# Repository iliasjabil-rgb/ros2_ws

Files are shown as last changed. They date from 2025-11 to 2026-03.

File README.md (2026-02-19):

# 🤖 Firmware Embarqué - Robot SRS

Ce dépôt contient le code source bas niveau (C++) pour les microcontrôleurs du robot SRS. Le système est divisé en deux cartes distinctes pour garantir la sécurité matérielle, la séparation des flux de puissance, et la gestion des périphériques.

## 🏗️ Architecture du Système

Le code communique avec un ordinateur central (Raspberry Pi / PC sous ROS 2) via un protocole série JSON non-bloquant à 115200 bauds.

```mermaid
graph LR
    classDef ros fill:#D95F02,stroke:#fff,stroke-width:2px,color:#fff,font-weight:bold;
    classDef mega fill:#00979D,stroke:#fff,stroke-width:2px,color:#fff,font-weight:bold;
    classDef uno fill:#17A2B8,stroke:#fff,stroke-width:2px,color:#fff,font-weight:bold;
    classDef hw fill:#E2E2E2,stroke:#333,stroke-width:1px,color:#333;

    subgraph CERVEAU ["Cerveau (PC / ROS 2 Humble)"]
        direction TB
        PC((Nœuds Python)):::ros
    end

    subgraph MEGA_SYS ["Sous-système Mouvement & Sécurité"]
        direction TB
        MEGA{Arduino MEGA}:::mega
        Drv["4x Drivers DM542"]:::hw
        Mot["4x Moteurs Z, Y, Magasin, Vérin"]:::hw
        FinsCourse["8x Fins de course (Min/Max)"]:::hw
        INA["4x Capteurs Puissance (INA260)"]:::hw
        ALM["3x Retours Alarme Drivers"]:::hw
        
        MEGA -->|STEP/DIR| Drv
        Drv ==>|Puissance| Mot
        FinsCourse -.->|Pullup LOW| MEGA
        INA -.->|Bus I2C| MEGA
        ALM -.->|Interrupt| MEGA
        Drv -.->|Feedback ALM| ALM
    end

    subgraph UNO_SYS ["Sous-système Périphériques"]
        direction TB
        UNO{Arduino UNO}:::uno
        Capteurs["I2C: IMU, Dist Laser, Temp"]:::hw
        Servos["4x Servomoteurs (Pince/Cam)"]:::hw
        Relais["6x Relais (Pompes, EV)"]:::hw
        LED["Ruban NeoPixel (D8)"]:::hw
        
        Capteurs -.->|Bus I2C| UNO
        UNO -->|PWM| Servos
        UNO -->|Digital HIGH/LOW| Relais
        UNO -->|Data 800kHz| LED
    end

    MEGA <==>|USB ttyACM0 - 10Hz| PC
    UNO <==>|USB ttyACM1 - 4Hz| PC
```
### Détail Matériel : Arduino MEGA (Nœud `001UC`)
Gère exclusivement les organes de puissance et la sécurité critique (hard-stop).

```mermaid
graph TD
    classDef mega fill:#00979D,stroke:#fff,color:#fff,font-weight:bold;
    classDef hw fill:#E2E2E2,stroke:#333,color:#333;
    classDef sensor fill:#1F77B4,stroke:#fff,color:#fff;
    classDef actuator fill:#D62728,stroke:#fff,color:#fff;

    MEGA[Arduino MEGA 2560]:::mega

    subgraph MOTEURS [Moteurs & Puissance]
        DRV[Drivers DM542]:::hw
        MOT[Moteurs Pas-à-Pas]:::actuator
        MEGA -->|Impulsions STEP / DIR| DRV
        DRV ===|Courant Fort| MOT
    end

    subgraph SECURITE [Sécurité Matérielle]
        FDC[8x Fins de Course Min/Max]:::sensor
        ALM[3x Alarmes Drivers ALM]:::sensor
        FDC -.->|Digital PULLUP LOW| MEGA
        ALM -.->|Digital PULLUP LOW| MEGA
    end

    subgraph ENERGIE [Mesure Énergie I2C]
        INA[4x Capteurs INA260]:::sensor
        INA -.->|Bus I2C 400kHz| MEGA
    end
```
### 2. Zoom Matériel : Arduino UNO (Périphériques)
### Détail Matériel : Arduino UNO (Nœud `002UC`)
Gère l'interface avec l'environnement (capteurs, vision, préhension).

```mermaid
graph TD
    classDef uno fill:#17A2B8,stroke:#fff,color:#fff,font-weight:bold;
    classDef sensor fill:#1F77B4,stroke:#fff,color:#fff;
    classDef actuator fill:#D62728,stroke:#fff,color:#fff;

    UNO[Arduino UNO R3]:::uno

    subgraph I2C_SENSORS [Capteurs I2C]
        IMU[LSM9DS1 - Centrale Inertielle]:::sensor
        TOF[VL53L0X - Distance Laser]:::sensor
        TEMP[MCP9808 - Température]:::sensor
        IMU -.->|SDA/SCL| UNO
        TOF -.->|SDA/SCL| UNO
        TEMP -.->|SDA/SCL| UNO
    end

    subgraph ACTIONNEURS [Actionneurs & Affichage]
        SRV[4x Servomoteurs]:::actuator
        REL[6x Relais de Puissance]:::actuator
        LED[Ruban LED NeoPixel]:::actuator
        UNO -->|Signaux PWM| SRV
        UNO -->|Digital LOW/HIGH| REL
        UNO -->|Data 800kHz| LED
    end
```
### 3. Graphe ROS 2 (Flux Logiciel)f
### Architecture Logicielle : Flux ROS 2
Ce graphe illustre comment le package `dual_serial_bridge` distribue les données entre le matériel et l'interface utilisateur.

```mermaid
graph LR
    classDef ros fill:#D95F02,stroke:#fff,color:#fff,font-weight:bold;
    classDef mega fill:#00979D,stroke:#fff,color:#fff;
    classDef uno fill:#17A2B8,stroke:#fff,color:#fff;
    classDef ui fill:#2CA02C,stroke:#fff,color:#fff,font-weight:bold;
    classDef topic fill:#f8f9fa,stroke:#333,color:#333;

    subgraph ROS2 [Espace de travail ROS 2]
        direction LR
        FOX((Foxglove Studio)):::ui
        M_DRV((mega_driver)):::ros
        U_DRV((uno_driver)):::ros
        
        %% Topics MEGA
        T_M_CMD>mega/command]:::topic
        T_M_POS>mega/positions]:::topic
        T_M_SEC>mega/limits & alarms]:::topic
        T_M_PWR>mega/power]:::topic
        
        %% Topics UNO
        T_U_CMD>uno/relais & servos /cmd]:::topic
        T_U_TEL>uno/imu, dist, temp]:::topic
        
        %% Connexions ROS
        FOX --> T_M_CMD --> M_DRV
        M_DRV --> T_M_POS & T_M_SEC & T_M_PWR --> FOX
        
        FOX --> T_U_CMD --> U_DRV
        U_DRV --> T_U_TEL --> FOX
    end
    
    HW_M[Arduino MEGA]:::mega
    HW_U[Arduino UNO]:::uno
    
    M_DRV <==>|Série ttyACM0 JSON| HW_M
    U_DRV <==>|Série ttyACM1 JSON| HW_U
```

## 📖 Dictionnaire d'API (Communication JSON)

L'entièreté de la communication entre ROS 2 et les Arduinos se fait via des chaînes JSON terminées par un retour à la ligne (`\n`).

### 1. Arduino MEGA (Mouvement & Sécurité)

**Télémétrie sortante (MEGA -> ROS 2) :**
* **Positions (10Hz) :** `{"src":"mega","pos":[Z, Magasin, Y, Verin]}`
* **Sécurité (10Hz) :** `{"src":"mega","mr":[0,1,0,0,0,0,0,0],"alm":[0,0,0,0]}` *(1 = Capteur touché ou Alarme activée)*
* **Puissance (2Hz) :** `{"src":"mega","pwr":[V1,I1,P1, V2,I2,P2, V3,I3,P3, V4,I4,P4]}`

**Commandes entrantes (ROS 2 -> MEGA) :**
* **Déplacer un axe :** `{"cmd":"move", "axis":1, "steps":200, "speed":1500.0}`
* **Arrêt d'urgence :** `{"cmd":"stop"}`
* **Reset Zéro (Software) :** `{"cmd":"home", "axis":0}` *(axis: 0 = tous, 1 à 4 = spécifique)*

### 2. Arduino UNO (Périphériques)

**Télémétrie sortante (UNO -> ROS 2) :**
* **Capteurs I2C (4Hz) :** `{"src":"uno", "imu_ok":1, "mcp_ok":1, "tof_ok":1, "temp_c":24.5, "dist_mm":150, "ax":0.0, "ay":0.0, "az":9.8, "gx":0.0, "gy":0.0, "gz":0.0, "mx":0.0, "my":0.0, "mz":0.0}`

**Commandes entrantes (ROS 2 -> UNO) :**
* **Contrôle Servomoteur :** `{"cmd":"servo", "id":1, "angle":90}` *(id: 1=CamZ, 2=CamY, 3=PinceRot, 4=PinceSerrage)*
* **Contrôle Relais :** `{"cmd":"relay", "id":1, "state":1}` *(id: 1=LedBlanche, 2=LedRGB, 3=Aspirateur, 4..6=EV)*
* **Contrôle Ruban LED (Fixe) :** `{"cmd":"led", "r":255, "g":0, "b":0, "a":255}` *(a = luminosité)*
* **Animation LED SRS :** `{"cmd":"led_effect", "state":1}`

---

## 🚀 Installation et Lancement

### 1. Flasher les Arduinos
1. Ouvrir le projet dans l'Arduino IDE.
2. Installer les bibliothèques requises : `ArduinoJson`, `AccelStepper`, `Adafruit INA260`, `Adafruit LSM9DS1`, `Adafruit MCP9808`, `Adafruit NeoPixel`, `VL53L0X`.
3. Téléverser dans les cartes respectives.

### 2. Lancer les Nœuds ROS 2
Une fois les cartes flashées et branchées en USB au PC/Raspberry, sourcez votre espace de travail ROS 2 et lancez les drivers Python du package `dual_serial_bridge` :

```bash
# Terminal 1 : Lancer le driver Mega
ros2 run dual_serial_bridge mega_driver

# Terminal 2 : Lancer le driver Uno
ros2 run dual_serial_bridge uno_driver
```

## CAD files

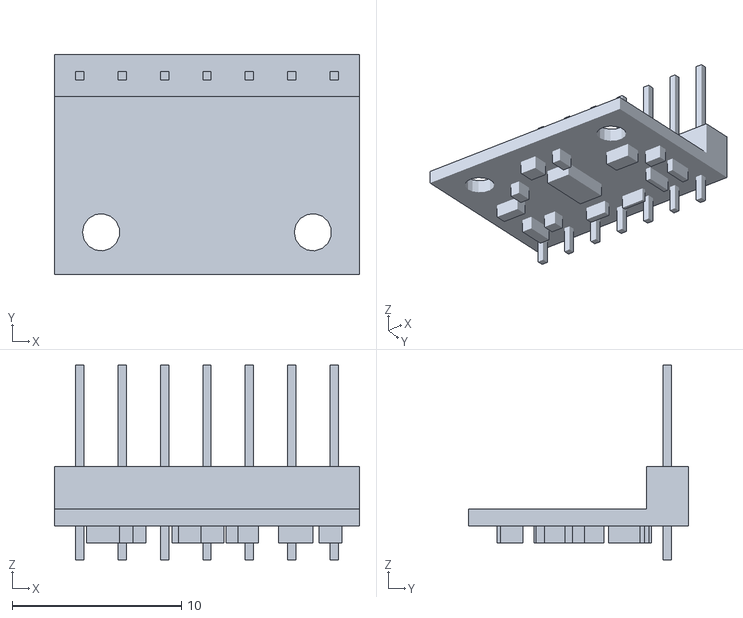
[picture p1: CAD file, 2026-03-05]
src/sysmap_package/meshes/cpt_distance.STL
18.0 x 13.0 x 11.5

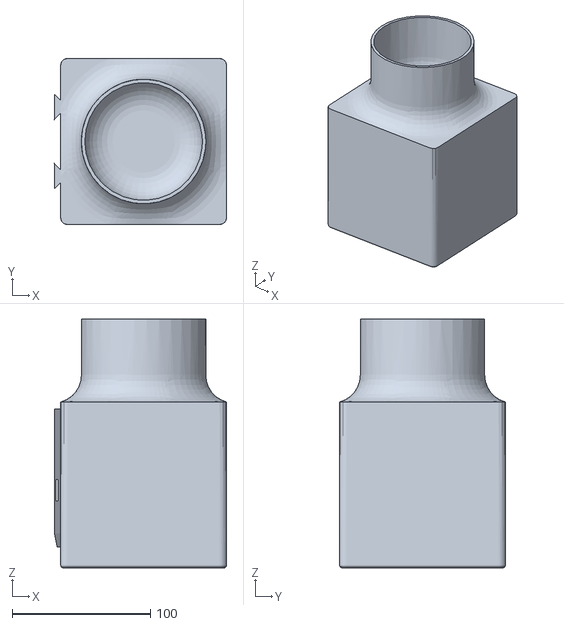
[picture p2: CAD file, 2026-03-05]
src/sysmap_package/meshes/boite_liquide.STL
124.5 x 120.0 x 180.0

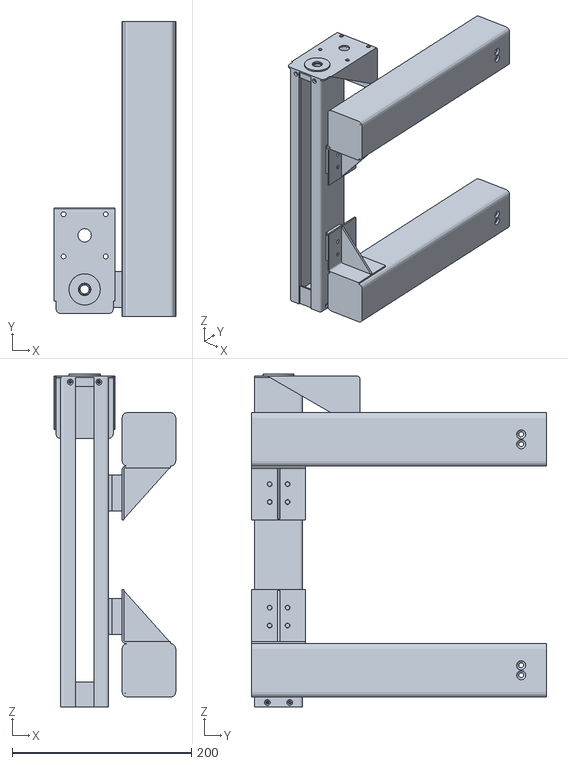
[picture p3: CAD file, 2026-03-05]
src/sysmap_package/meshes/gliss_poteaux.STL
135.8 x 329.0 x 372.0

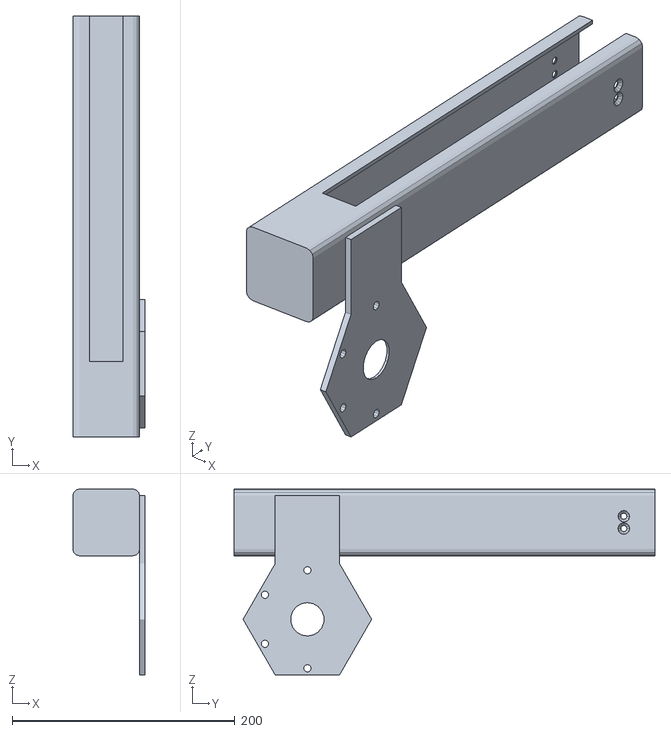
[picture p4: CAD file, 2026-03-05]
src/sysmap_package/meshes/gliss_bras.STL
65.0 x 378.0 x 167.0

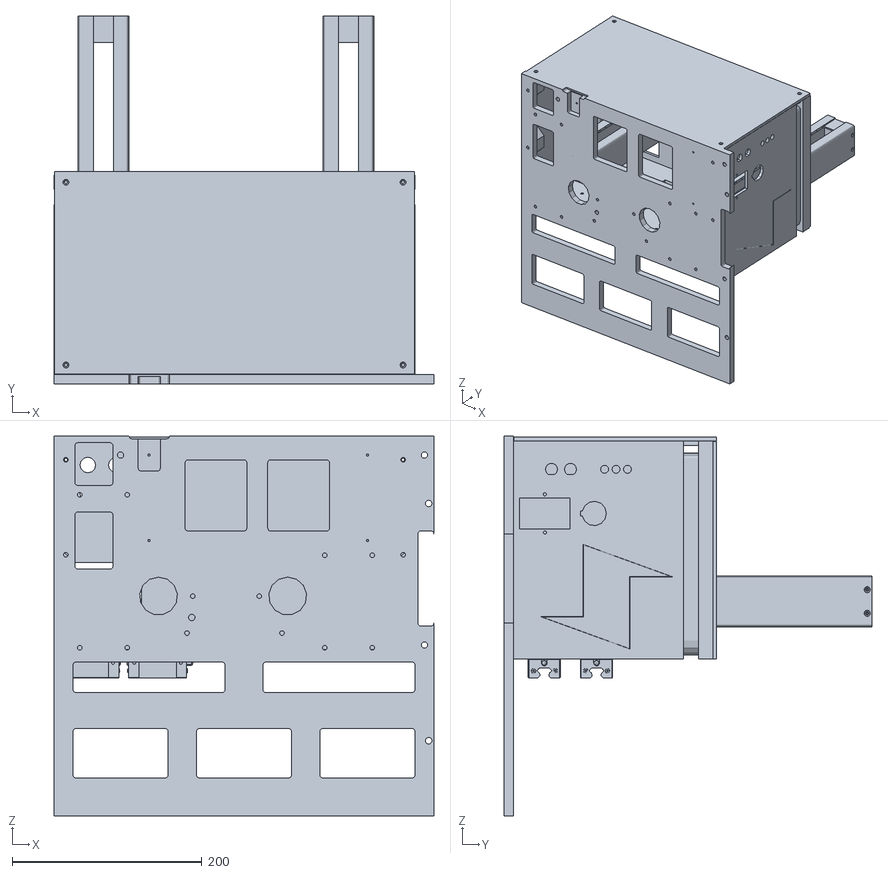
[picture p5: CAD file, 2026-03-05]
src/sysmap_package/meshes/base.STL
400.0 x 387.5 x 400.0

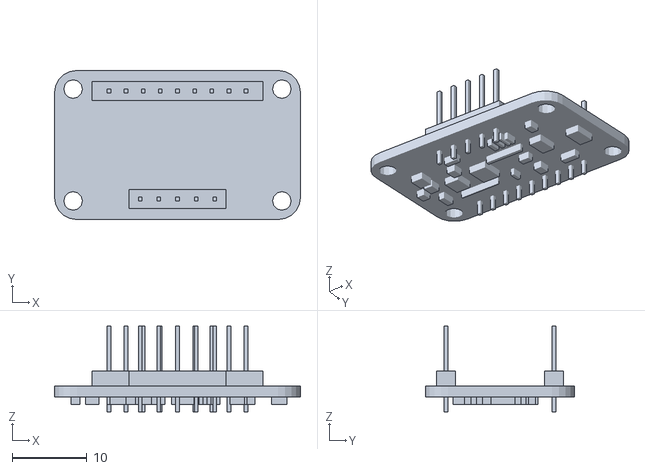
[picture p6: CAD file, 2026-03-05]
src/sysmap_package/meshes/IMU.STL
33.0 x 20.0 x 11.5

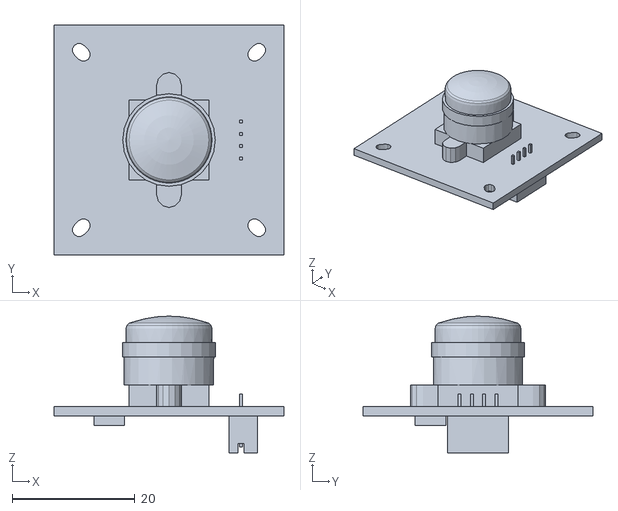
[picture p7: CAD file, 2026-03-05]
src/sysmap_package/meshes/camera.STL
37.5 x 37.5 x 22.3

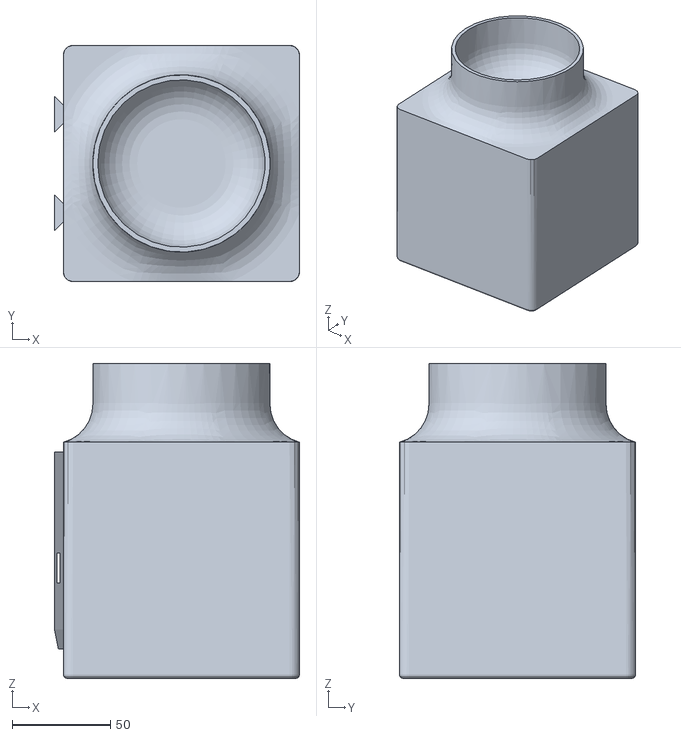
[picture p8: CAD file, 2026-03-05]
src/sysmap_package/meshes/boite_frottis.STL
124.5 x 120.0 x 160.0

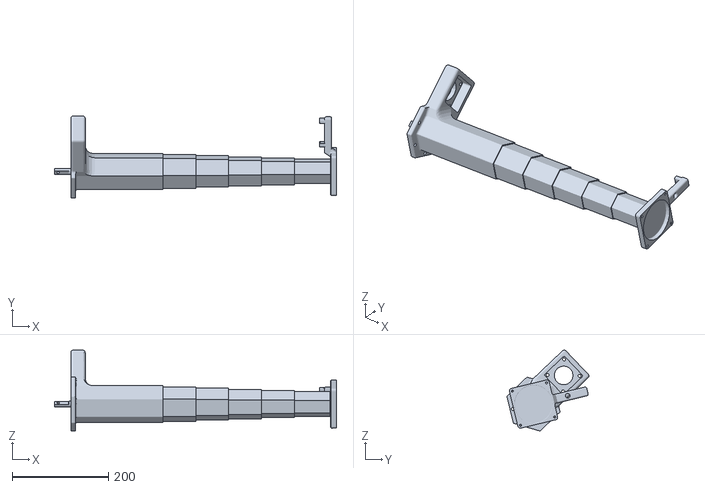
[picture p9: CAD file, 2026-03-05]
src/sysmap_package/meshes/verin.STL
586.3 x 170.5 x 168.1

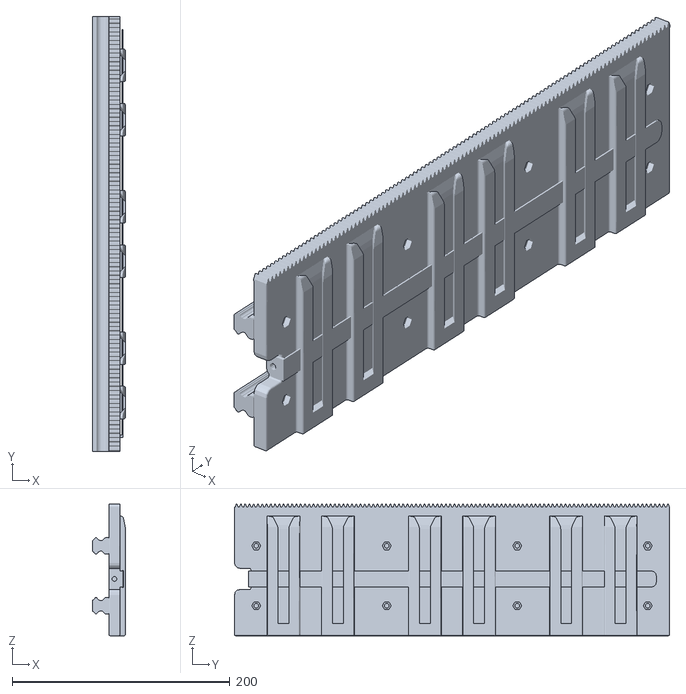
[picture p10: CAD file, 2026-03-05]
src/sysmap_package/meshes/gliss_boites.STL
30.0 x 400.0 x 121.1

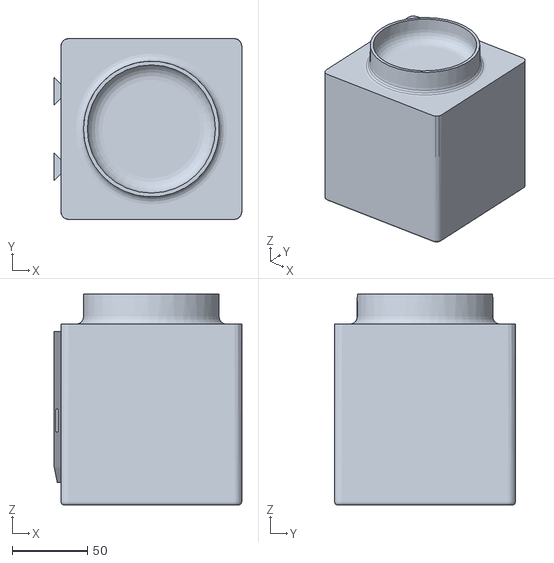
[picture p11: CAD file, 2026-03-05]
src/sysmap_package/meshes/boite_solide.STL
124.5 x 120.0 x 140.0

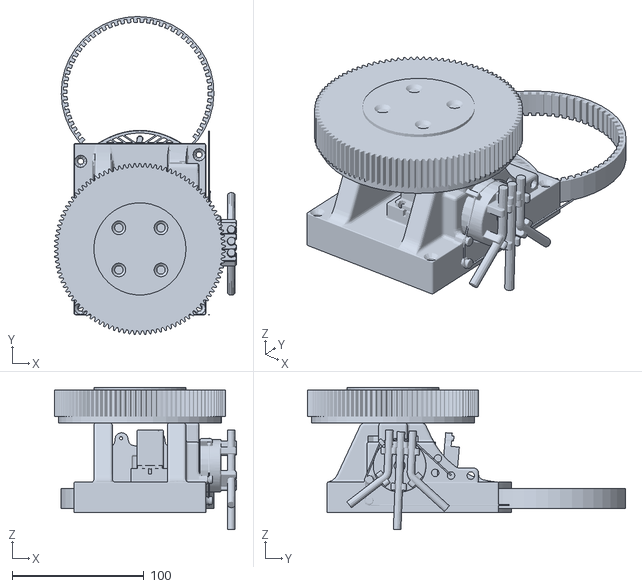
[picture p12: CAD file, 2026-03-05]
src/sysmap_package/meshes/rot_pince.STL
138.4 x 241.5 x 108.1

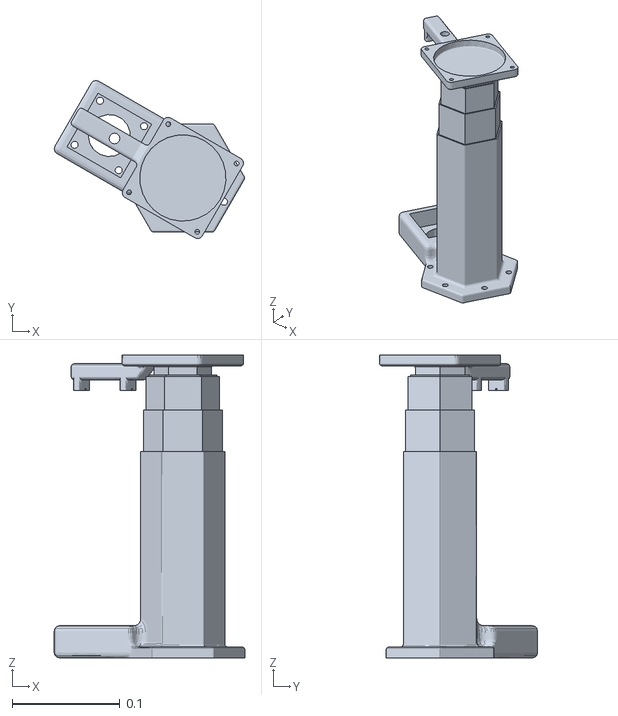
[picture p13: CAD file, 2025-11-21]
src/sysmap_package/meshes/verrin.STL
0.177 x 0.147 x 0.281

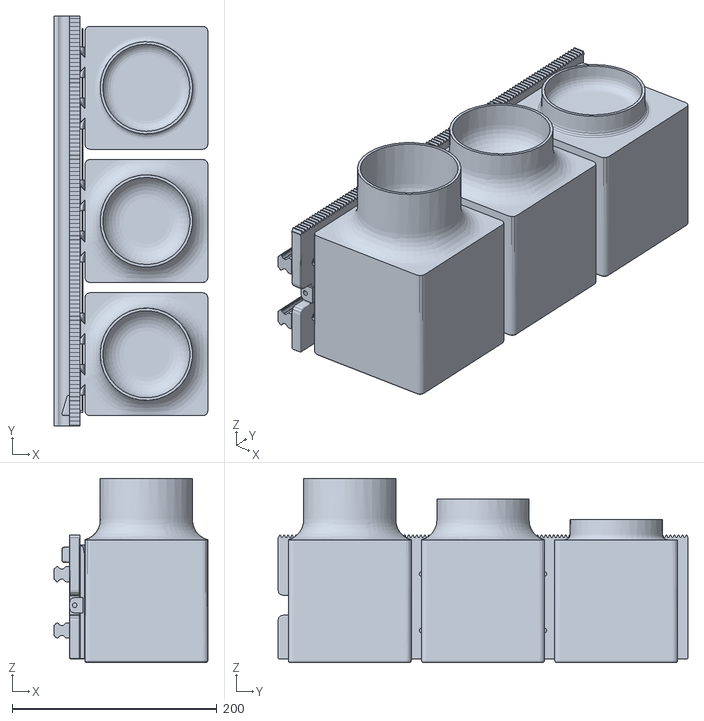
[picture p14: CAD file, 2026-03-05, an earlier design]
src/sysmap_package/meshes/gliss_boites_old.STL
150.0 x 400.0 x 180.0

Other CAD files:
src/sysmap_package/meshes/gliss_poteaux_old.STL
src/sysmap_package/meshes/base_old.STL
src/sysmap_package/meshes/rot_pince_old.STL
src/sysmap_package/meshes/gliss_bras_old.STL

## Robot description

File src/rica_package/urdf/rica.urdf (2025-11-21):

<?xml version="1.0"?>
<robot name="RICA">

  <material name="blue">
    <color rgba="0 0 0.8 1"/>
  </material>

  <material name="white">
    <color rgba="1 1 1 1"/>
  </material>

  <link name="base_link">
    <visual>
      <geometry>
        <box size="0.54 0.39 0.15"/>
      </geometry>
    </visual>
  </link>

  <link name="front_left_leg">
    <visual>
      <geometry>
        <box size="0.41 0.04 0.1"/>
      </geometry>
      <origin rpy="0 1.57075 0" xyz="0 0.06 0.17"/>
      <material name="blue"/>
    </visual>
    <collision>
      <geometry>
        <box size="0.41 0.04 0.1"/>
      </geometry>
      <origin rpy="0 1.57075 0" xyz="0 0.06 0.17"/>
    </collision>
  </link>

  <joint name="base_to_front_left_leg" type="revolute">
    <axis xyz="0 1 0"/>
    <limit effort="1000.0" lower="0.0" upper="6.28" velocity="0.5"/>
    <parent link="base_link"/>
    <child link="front_left_leg"/>
    <origin xyz="0.20 0.195 -0.04"/>
  </joint>

  <link name="front_right_leg">
    <visual>
      <geometry>
        <box size="0.41 0.04 0.1"/>
      </geometry>
      <origin rpy="0 1.57075 0" xyz="0 -0.06 0.17"/>
    </visual>
    <collision>
      <geometry>
        <box size="0.41 0.04 0.1"/>
      </geometry>
      <origin rpy="0 1.57075 0" xyz="0 -0.06 0.17"/>
    </collision>
  </link>

  <joint name="base_to_front_right_leg" type="revolute">
    <axis xyz="0 1 0"/>
    <limit effort="1000.0" lower="0.0" upper="6.28" velocity="0.5"/>
    <parent link="base_link"/>
    <child link="front_right_leg"/>
    <origin xyz="0.20 -0.195 -0.04"/>
  </joint>

    <link name="back_left_leg">
    <visual>
      <geometry>
        <box size="0.41 0.04 0.1"/>
      </geometry>
      <origin rpy="0 1.57075 0" xyz="0 0.06 0.17"/>
      <material name="white"/>
    </visual>
    <collision>
      <geometry>
        <box size="0.41 0.04 0.1"/>
      </geometry>
      <origin rpy="0 1.57075 0" xyz="0 0.06 0.17"/>
    </collision>
  </link>

  <joint name="base_to_back_left_leg" type="revolute">
    <axis xyz="0 1 0"/>
    <limit effort="1000.0" lower="-6.28" upper="0.0" velocity="-0.5"/>
    <parent link="base_link"/>
    <child link="back_left_leg"/>
    <origin xyz="-0.20 0.195 -0.04"/>
  </joint>

    <link name="back_right_leg">
    <visual>
      <geometry>
        <box size="0.41 0.04 0.1"/>
      </geometry>
      <origin rpy="0 1.57075 0" xyz="0 -0.06 0.17"/>
      <material name="white"/>
    </visual>
    <collision>
      <geometry>
        <box size="0.41 0.04 0.1"/>
      </geometry>
      <origin rpy="0 1.57075 0" xyz="0 -0.06 0.17"/>
    </collision>  
  </link>

  <joint name="base_to_back_right_leg" type="revolute">
    <axis xyz="0 1 0"/>
    <limit effort="1000.0" lower="-6.28" upper="0.0" velocity="0.5"/>
    <parent link="base_link"/>
    <child link="back_right_leg"/>
    <origin xyz="-0.20 -0.195 -0.04"/>
  </joint>

    <link name="left_side">
    <visual>
      <geometry>
        <box size="0.54 0.04 0.15"/>
      </geometry>
      <origin rpy="0 0 0" xyz="0 0.02 0"/>
      <material name="blue"/>
    </visual>
  </link>

<joint name="base_to_left_side" type="revolute">
  <parent link="base_link"/><child link="left_side"/>
  <origin xyz="0 0.195 0"/>
  <axis xyz="0 1 0"/>
  <limit lower="-1.57" upper="1.57" effort="50" velocity="1.0"/>
</joint>

    <link name="right_side">
    <visual>
      <geometry>
        <box size="0.54 0.04 0.15"/>
      </geometry>
      <origin rpy="0 0 0" xyz="0 -0.02 0"/>
      <material name="white"/>
    </visual>
  </link>

 <joint name="base_to_right_side" type="revolute">
  <parent link="base_link"/><child link="right_side"/>
  <origin xyz="0 -0.195 0"/>
  <axis xyz="0 1 0"/>
  <limit lower="-1.57" upper="1.57" effort="50" velocity="1.0"/>
</joint>
</robot>

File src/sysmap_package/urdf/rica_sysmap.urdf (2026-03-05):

<?xml version="1.0" encoding="utf-8"?>
<robot name="RICA_SYSMAP_ARM">
<material name="blue"><color rgba="0 0 0.8 1"/></material>
<material name="white"><color rgba="1 1 1 1"/></material>
<material name="grey"><color rgba="0.5 0.5 0.5 1"/></material>
<material name="yellow"><color rgba="1 1 0 1"/></material>
<link name="base_link">
<visual>
<geometry><box size="0.54 0.39 0.15"/></geometry>
<material name="blue"/>
</visual>
<collision>
<geometry><box size="0.54 0.39 0.15"/></geometry>
<origin xyz="0 0 0"/>
</collision>
</link>
<link name="front_left_leg">
<visual>
<geometry><box size="0.41 0.04 0.1"/></geometry>
<origin rpy="0 1.57075 0" xyz="0 0.06 0.17"/>
<material name="white"/>
</visual>
</link>
<joint name="base_to_front_left_leg" type="revolute">
<axis xyz="0 1 0"/>
<limit effort="1000.0" lower="0.0" upper="6.28" velocity="0.5"/>
<parent link="base_link"/>
<child link="front_left_leg"/>
<origin xyz="0.20 0.195 -0.04"/>
</joint>
<joint name="rica_to_arm_base" type="fixed">
<parent link="base_link"/>
<child link="base"/>
<origin xyz="0.1 0 0.1" rpy="0 0 0"/>
</joint>
<link name="base">
<visual>
<origin xyz="-0.30 0.205 -0.04" rpy=" 1.57075 0 1.57" />
<geometry><mesh filename="package://sysmap_package/meshes/base.STL" scale="0.001 0.001 0.001" /></geometry>
<material name="blue"/>
</visual>
</link>
<link name="gliss_poteaux">
<visual>
<geometry><mesh filename="package://sysmap_package/meshes/gliss_poteaux.STL" scale="0.001 0.001 0.001" /></geometry>
<material name="grey"/>
</visual>
</link>
<joint name="gliss_poteaux" type="prismatic">
<origin xyz="-0.18 -0.78 0.5" rpy="-1.57075 0 0" />
<parent link="base" />
<child link="gliss_poteaux" />
<axis xyz="0 1 0" />
<limit lower="0" upper="0.175" effort="100" velocity="0.1" />
</joint>
<link name="gliss_bras">
<visual>
<geometry><mesh filename="package://sysmap_package/meshes/gliss_bras.STL" scale="0.001 0.001 0.001" /></geometry>
<material name="yellow"/>
</visual>
</link>
<joint name="gliss_bras" type="prismatic">
<origin xyz="-0.10 0.005 0.65" rpy="1.57 0 1.57" />
<parent link="gliss_poteaux" />
<child link="gliss_bras" />
<axis xyz="0 1 0" />
<limit lower="0" upper="0.28" effort="100" velocity="0.1" />
</joint>
<link name="verin">
<visual>
<geometry><mesh filename="package://sysmap_package/meshes/verin.STL" scale="0.001 0.001 0.001" /></geometry>
<material name="grey"/>
</visual>
</link>
<joint name="verin" type="prismatic">
<origin xyz="0.025 0 -1.025" rpy="0 0 0" />
<parent link="gliss_bras" />
<child link="verin" />
<axis xyz="-1 0 0" />
<limit lower="0" upper="0.32" effort="100" velocity="0.1" />
</joint>
<link name="rot_pince">
<visual>
<geometry><mesh filename="package://sysmap_package/meshes/rot_pince.STL" scale="0.001 0.001 0.001" /></geometry>
<material name="white"/>
</visual>
</link>
<joint name="rot_pince" type="revolute">
<origin xyz="1.68 -0.02 0.95 " rpy="0 4.75 0" />
<parent link="verin" />
<child link="rot_pince" />
<axis xyz="0 0 -1" />
<limit lower="-3.14" upper="3.14" effort="10" velocity="1.0" />
</joint>
<link name="gliss_boites">
<visual>
<geometry><mesh filename="package://sysmap_package/meshes/gliss_boites.STL" scale="0.001 0.001 0.001" /></geometry>
<material name="grey"/>
</visual>
</link>
<joint name="gliss_boites" type="prismatic">
<origin xyz="-0.28 0.2 -1" rpy="0 0 0" />
<parent link="base" />
<child link="gliss_boites" />
<axis xyz="0 -1 0" />
<limit lower="0" upper="0.21" effort="50" velocity="0.1" />
</joint>
<link name="camera_fixed_link">
<visual>
<geometry><mesh filename="package://sysmap_package/meshes/camera0.STL" scale="0.001 0.001 0.001" /></geometry>
<material name="grey"/>
</visual>
</link>
<joint name="gliss_bras_to_camera_fixed" type="fixed">
<parent link="gliss_bras" />
<child link="camera_fixed_link" />
<origin xyz="-0.31 0 -0.09" rpy="0 0.4 0" />
</joint>
<link name="camera_eye_link">
<visual>
<geometry><mesh filename="package://sysmap_package/meshes/camera0.STL" scale="0.001 0.001 0.001" /></geometry>
<material name="grey"/>
</visual>
</link>
<joint name="pince_to_camera" type="fixed">
<parent link="rot_pince" />
<child link="camera_eye_link" />
<origin xyz="0.05 0 -0.035" rpy="0 0 0" />
</joint>
<link name="tof_sensor_link">
<visual>
<geometry><mesh filename="package://sysmap_package/meshes/cpt_distance0.STL" scale="0.001 0.001 0.001" /></geometry>
<material name="grey"/>
</visual>
</link>
<joint name="pince_to_tof" type="fixed">
<parent link="rot_pince" />
<child link="tof_sensor_link" />
<origin xyz="0 0.045 -0.075" rpy="0 0 0" />
</joint>
<link name="uno_imu_link">
<visual>
<geometry><mesh filename="package://sysmap_package/meshes/IMU0.STL" scale="0.001 0.001 0.001" /></geometry>
<material name="grey"/>
</visual>
</link>
<joint name="base_to_imu" type="fixed">
<parent link="rot_pince" />
<child link="uno_imu_link" />
<origin xyz="0.04 0.045 -0.075" rpy="0 0 0" />
</joint>
<link name="boite_1">
<visual>
<geometry><mesh filename="package://sysmap_package/meshes/boite_solide.STL" scale="0.001 0.001 0.001" /></geometry>
<material name="grey"/>
</visual>
</link>
<joint name="rail_to_boite_1" type="fixed">
<parent link="gliss_boites" />
<child link="boite_1" />
<origin xyz="-0.14 0 0.03" rpy="0 0 0" />
</joint>
<link name="boite_2">
<visual>
<geometry><mesh filename="package://sysmap_package/meshes/boite_liquide.STL" scale="0.001 0.001 0.001" /></geometry>
<material name="grey"/>
</visual>
</link>
<joint name="rail_to_boite_2" type="fixed">
<parent link="gliss_boites" />
<child link="boite_2" />
<origin xyz="-0.1 0.28 0.03" rpy="0 0 0" />
</joint>
<link name="boite_3">
<visual>
<geometry><mesh filename="package://sysmap_package/meshes/boite_frottis.STL" scale="0.001 0.001 0.001" /></geometry>
<material name="grey"/>
</visual>
</link>
<joint name="rail_to_boite_3" type="fixed">
<parent link="gliss_boites" />
<child link="boite_3" />
<origin xyz="-0.15 0.15 0" rpy="0 0 0" />
</joint>
</robot>

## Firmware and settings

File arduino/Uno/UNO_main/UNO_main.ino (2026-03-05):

/**
* ============================================================================
* FICHIER : UNO_main.ino (V4.1 - Avec Calibration IMU)
* ROLE    : Programme principal de l'Arduino Uno.
* - Gestion des actionneurs secondaires (Servos, Relais, LED)
* - Lecture des capteurs I2C (IMU, Température, Distance ToF)
* - Parsing JSON "manuel" optimisé pour économiser la RAM de la Uno.
* - Calibrage automatique du gyroscope au démarrage.
* ============================================================================
*/
 
#include <Wire.h>
#include <Servo.h>
#include <Adafruit_NeoPixel.h>
#include <Adafruit_LSM9DS1.h>
#include <Adafruit_Sensor.h>
#include <Adafruit_MCP9808.h>
#include <VL53L0X.h>
 
#include "pins_uno.h"
#include "protocol.h"
 
/**
* ============================================================================
* CONFIGURATION MATÉRIELLE (Drapeaux d'activation)
* ============================================================================
*/
#define USE_IMU      1
#define USE_MCP9808  1
#define USE_VL53L0X  1
 
const uint32_t TELEMETRY_INTERVAL_MS = 250; // Télémétrie à 4 Hz
 
/**
* ============================================================================
* VARIABLES GLOBALES ET OBJETS
* ============================================================================
*/
// --- Ruban LED RGB ---
#define LED_COUNT UNO_001LED_COUNT
Adafruit_NeoPixel strip(LED_COUNT, UNO_001LED_PIN, NEO_GRB + NEO_KHZ800);
 
// --- Capteurs I2C ---
Adafruit_LSM9DS1 imu = Adafruit_LSM9DS1();
Adafruit_MCP9808 mcp9808 = Adafruit_MCP9808();
VL53L0X tof;
 
// --- Actionneurs et Communication ---
Servo servo1, servo2, servo3, servo4;
String rx; // Buffer de réception série
 
// --- États du système ---
bool imu_ok = false;
bool mcp_ok = false;
bool tof_ok = false;

// --- Offsets de calibration du Gyroscope ---
float gyro_offset_x = 0.0f;
float gyro_offset_y = 0.0f;
float gyro_offset_z = 0.0f;
 
/**
* ============================================================================
* FONCTIONS UTILITAIRES
* ============================================================================
*/
 
// Écrit proprement sur une sortie digitale si la broche est valide
void digitalSafeWrite(int8_t pin, int level) {
  if (pin >= 0) {
    pinMode(pin, OUTPUT);
    digitalWrite(pin, level);
  }
}
 
/**
* ============================================================================
* SETUP : INITIALISATION
* ============================================================================
*/
void setup() {
  Serial.begin(115200);          
  send_json(F("{\"src\":\"uno\",\"event\":\"BOOT_UNO_MAIN_DEBUT\"}"));
  // Pré-allocation pour limiter la fragmentation RAM avec la String de réception
  rx.reserve(128);
  // --- Initialisation Fin de course ---
  pinMode(UNO_001FC_PIN, INPUT_PULLUP);
 
  // --- Initialisation I2C Haut Débit ---
  Wire.begin();
  Wire.setClock(400000);
 
#if USE_IMU
  if (!imu.begin()) {
    imu_ok = false;
    send_json(F("{\"src\":\"uno\",\"event\":\"imu_init_failed\"}"));
  } else {
    imu_ok = true;
    send_json(F("{\"src\":\"uno\",\"event\":\"imu_ok_starting_calibration\"}"));
    imu.setupAccel(imu.LSM9DS1_ACCELRANGE_2G);
    imu.setupGyro(imu.LSM9DS1_GYROSCALE_245DPS);
    imu.setupMag(imu.LSM9DS1_MAGGAIN_4GAUSS);

    // --- CALIBRATION DU GYROSCOPE (Prend environ 1 à 2 secondes) ---
    // NE PAS BOUGER LE CAPTEUR PENDANT CE TEMPS
    const int NUM_SAMPLES = 200;
    float sum_x = 0, sum_y = 0, sum_z = 0;
    sensors_event_t a_evt, g_evt, m_evt, t_evt;
    
    for (int i = 0; i < NUM_SAMPLES; i++) {
        imu.getEvent(&a_evt, &g_evt, &m_evt, &t_evt);
        sum_x += g_evt.gyro.x;
        sum_y += g_evt.gyro.y;
        sum_z += g_evt.gyro.z;
        delay(5);
    }
    
    // Calcul de la moyenne du bruit au repos
    gyro_offset_x = sum_x / NUM_SAMPLES;
    gyro_offset_y = sum_y / NUM_SAMPLES;
    gyro_offset_z = sum_z / NUM_SAMPLES;
    
    send_json(F("{\"src\":\"uno\",\"event\":\"imu_calibrated\"}"));
  }
#endif
 
#if USE_MCP9808
  if (mcp9808.begin(0x1F)) { // Adresse par défaut
    mcp_ok = true;
    mcp9808.setResolution(3);
    send_json(F("{\"src\":\"uno\",\"event\":\"mcp9808_temp_ok\"}"));
  } else {
    mcp_ok = false;
    send_json(F("{\"src\":\"uno\",\"event\":\"mcp9808_temp_init_failed\"}"));
  }
#endif
 
#if USE_VL53L0X
  if (tof.init()) {
    tof.setTimeout(50);
    tof_ok = true;
    send_json(F("{\"src\":\"uno\",\"event\":\"vl53l0x_dist_ok\"}"));
  } else {
    tof_ok = false;
    send_json(F("{\"src\":\"uno\",\"event\":\"vl53l0x_dist_init_failed\"}"));
  }
#endif
 
  // --- Initialisation Relais ---
  digitalSafeWrite(UNO_001XR_PIN, LOW);  // Ruban LED Blanc coupé
  digitalSafeWrite(UNO_002XR_PIN, HIGH); // Relais Ruban LED RGB activé pour l'allumage
  digitalSafeWrite(UNO_003XR_PIN, LOW);
  digitalSafeWrite(UNO_004XR_PIN, LOW);
  digitalSafeWrite(UNO_005XR_PIN, LOW);
  digitalSafeWrite(UNO_006XR_PIN, LOW);
 
  // --- Initialisation Servos ---
  if (UNO_001SV_PIN >= 0) { servo1.attach(UNO_001SV_PIN, 500, 2500); servo1.write(90); }
  if (UNO_002SV_PIN >= 0) { servo2.attach(UNO_002SV_PIN, 500, 2500); servo2.write(90); }
  if (UNO_003SV_PIN >= 0) { servo3.attach(UNO_003SV_PIN, 500, 2500); servo3.write(89); }
  if (UNO_004SV_PIN >= 0) { servo4.attach(UNO_004SV_PIN, 500, 2500); servo4.write(89); }
 
  // --- Initialisation Ruban LED ---
  if (UNO_001LED_PIN >= 0) {
    delay(10);
    strip.begin();
    strip.setBrightness(30);
    for (int i = 0; i < LED_COUNT; i++) {
      strip.setPixelColor(i, strip.Color(255, 255, 255));
    }
    strip.show(); 
  }
 
  send_json(String("{\"board\":\"") + UNO_BOARD_ID + "\",\"fw\":\"" + UNO_FW_VERSION + "\",\"event\":\"boot_ready\"}");
}
 
/**
* ============================================================================
* FONCTION : PARSING DES COMMANDES (Optimisé RAM)
* ============================================================================
*/
void handleCmd(const String& line) {
 
  // ----------------------------------------------------------------
  // COMMANDE : SERVO
  // ----------------------------------------------------------------
  if (line.indexOf("\"cmd\":\"servo\"") >= 0) {
    int id = 1, ang = 90, p;
 
    p = line.indexOf("\"id\":");    if (p >= 0) id = line.substring(p + 5).toInt();
    p = line.indexOf("\"angle\":"); if (p >= 0) ang = line.substring(p + 8).toInt();
 
    int cmd_angle = constrain(ang, 0, 180);
 
    if      (id == 1 && UNO_001SV_PIN >= 0) servo1.write(cmd_angle);
    else if (id == 2 && UNO_002SV_PIN >= 0) servo2.write(cmd_angle);
    else if (id == 3 && UNO_003SV_PIN >= 0) servo3.write(cmd_angle);
    else if (id == 4 && UNO_004SV_PIN >= 0) servo4.write(cmd_angle);
 
    send_json(String("{\"src\":\"uno\",\"event\":\"servo\",\"id\":") + id + ",\"angle_cmd\":" + cmd_angle + "}");
  }
 
  // ----------------------------------------------------------------
  // COMMANDE : RELAY
  // ----------------------------------------------------------------
  else if (line.indexOf("\"cmd\":\"relay\"") >= 0) {
    int id = 1, st = 0, p;
 
    p = line.indexOf("\"id\":");    if (p >= 0) id = line.substring(p + 5).toInt();
    p = line.indexOf("\"state\":"); if (p >= 0) st = line.substring(p + 8).toInt();
 
    uint8_t pin = (id == 1) ? UNO_001XR_PIN :
                  (id == 2) ? UNO_002XR_PIN :
                  (id == 3) ? UNO_003XR_PIN :
                  (id == 4) ? UNO_004XR_PIN :
                  (id == 5) ? UNO_005XR_PIN :
                  (id == 6) ? UNO_006XR_PIN : 0;
 
    digitalSafeWrite(pin, st ? HIGH : LOW);
    send_json(String("{\"src\":\"uno\",\"event\":\"relay\",\"id\":") + id + ",\"state\":" + st + "}");
  }
 
  // ----------------------------------------------------------------
  // COMMANDE : LED (Couleur Fixe & Pilotage via ROS 2)
  // ----------------------------------------------------------------
  else if (line.indexOf("\"cmd\":\"led\"") >= 0) {
    int r = 0, g = 0, b = 0, a = 80, id = -1, p;
 
    p = line.indexOf("\"id\":"); if (p >= 0) id = line.substring(p + 5).toInt();
    p = line.indexOf("\"r\":");  if (p >= 0) r  = line.substring(p + 4).toInt();
    p = line.indexOf("\"g\":");  if (p >= 0) g  = line.substring(p + 4).toInt();
    p = line.indexOf("\"b\":");  if (p >= 0) b  = line.substring(p + 4).toInt();
    p = line.indexOf("\"a\":");  if (p >= 0) a  = line.substring(p + 4).toInt();
 
    r = constrain(r, 0, 255); g = constrain(g, 0, 255);
    b = constrain(b, 0, 255); a = constrain(a, 0, 255);
 
    if (UNO_001LED_PIN >= 0) {
      strip.setBrightness(a); 
      if (id >= 0 && id < LED_COUNT) {
        strip.setPixelColor(id, strip.Color(r, g, b));
      } else {
        for (int i = 0; i < LED_COUNT; i++) strip.setPixelColor(i, strip.Color(r, g, b));
      }
      strip.show();
    }
  }
}
 
/**
* ============================================================================
* BOUCLE PRINCIPALE
* ============================================================================
*/
void loop() {
  // --- 1. Lecture asynchrone du port Série ---
  while (Serial.available()) {
    char c = Serial.read();
    if (c == '\n') {
      handleCmd(rx);
      rx = "";
    } else if (c != '\r') {
      rx += c;
    }
  }
 
  // --- 2. SÉCURITÉ FIN DE COURSE (Servo 4 - Serrage Pince) ---
  if (digitalRead(UNO_001FC_PIN) == LOW) {
    if (servo4.read() > 90) {
      servo4.write(90);
    }
  }
  // --- 3. Télémétrie périodique ---
  static uint32_t t0 = 0;
  uint32_t ms = millis();
 
  if (ms - t0 > TELEMETRY_INTERVAL_MS) {
    t0 = ms;
 
    // Variables par défaut
    float ax = 0.0f, ay = 0.0f, az = 0.0f;
    float gx = 0.0f, gy = 0.0f, gz = 0.0f;
    float mx = 0.0f, my = 0.0f, mz = 0.0f;
    float temp_c = 0.0f;
    uint16_t dist_mm = 0;
 
    // Lecture IMU
    if (imu_ok) {
      sensors_event_t a_event, g_event, m_event, temp_event;
      imu.getEvent(&a_event, &g_event, &m_event, &temp_event);
 
      ax = a_event.acceleration.x; ay = a_event.acceleration.y; az = a_event.acceleration.z;
      
      // Soustraction de l'offset et Conversion en Radians par seconde (rad/s)
      gx = (g_event.gyro.x - gyro_offset_x) * 0.0174533f;         
      gy = (g_event.gyro.y - gyro_offset_y) * 0.0174533f;         
      gz = (g_event.gyro.z - gyro_offset_z) * 0.0174533f;

      mx = m_event.magnetic.x;     my = m_event.magnetic.y;     mz = m_event.magnetic.z;
    }
 
    // Lecture Température
    if (mcp_ok) temp_c = mcp9808.readTempC();
 
    // Lecture ToF (Laser)
    if (tof_ok) {
      dist_mm = tof.readRangeSingleMillimeters();
      if (tof.timeoutOccurred()) send_json(F("{\"src\":\"uno\",\"event\":\"VL53_dist_TIMEOUT\"}"));
    }
 
    // ------------------------------------------------------------------
    // FORMATAGE MANUEL DU JSON
    // ------------------------------------------------------------------
    Serial.print(F("{\"src\":\"uno\""));
 
    Serial.print(F(",\"imu_ok\":")); Serial.print(imu_ok ? 1 : 0);
    Serial.print(F(",\"mcp_ok\":")); Serial.print(mcp_ok ? 1 : 0);
    Serial.print(F(",\"tof_ok\":")); Serial.print(tof_ok ? 1 : 0);
 
    Serial.print(F(",\"temp_c\":"));  Serial.print(temp_c, 2);
    Serial.print(F(",\"dist_mm\":")); Serial.print(dist_mm);
 
    Serial.print(F(",\"ax\":")); Serial.print(ax, 3);
    Serial.print(F(",\"ay\":")); Serial.print(ay, 3);
    Serial.print(F(",\"az\":")); Serial.print(az, 3);
 
    // Précision augmentée à 4 décimales pour les radians
    Serial.print(F(",\"gx\":")); Serial.print(gx, 4);
    Serial.print(F(",\"gy\":")); Serial.print(gy, 4);
    Serial.print(F(",\"gz\":")); Serial.print(gz, 4);
 
    Serial.print(F(",\"mx\":")); Serial.print(mx, 3);
    Serial.print(F(",\"my\":")); Serial.print(my, 3);
    Serial.print(F(",\"mz\":")); Serial.print(mz, 3);
 
    Serial.println('}'); 
  }
}

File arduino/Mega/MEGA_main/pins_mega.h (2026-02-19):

#pragma once
#include <Arduino.h>

/**
 * ============================================================================
 * FICHIER : pins_mega.h
 * ROLE    : Définition du mapping matériel (broches) pour l'Arduino Mega.
 * Centralise toutes les connexions physiques du robot.
 * ============================================================================
 */

/* --- IDENTIFICATION DU NŒUD --- */
#define MEGA_BOARD_ID   "001UC_ARDUINO_MEGA"
#define MEGA_FW_VERSION "1.0"

/*** ======== MOTEURS PAS-A-PAS (DRIVERS 002DM) =========
 *  001MO : Colonne
 *  002MO : Stockage
 *  003MO : Déplacement tige
 *  004MO : Tige rétractable

/**
 * ============================================================================
 * MOTEURS PAS-À-PAS (DRIVERS 002DM)
 * ============================================================================
 * Chaque driver moteur utilise 3 broches de contrôle :
 * - STEP : Impulsion pour avancer d'un pas
 * - DIR  : Sens de rotation
 * - EN   : Activation / Désactivation de la puissance (Enable)
 */

// Moteur 1 (001MO) : Colonne Z (Élévation principale)
static const uint8_t MEGA_001MO_STEP = 22;
static const uint8_t MEGA_001MO_DIR  = 23;
static const uint8_t MEGA_001MO_EN   = 24;

// Moteur 2 (002MO) : Stockage (Gestion du magasin)
static const uint8_t MEGA_002MO_STEP = 25;
static const uint8_t MEGA_002MO_DIR  = 26;
static const uint8_t MEGA_002MO_EN   = 27;

// Moteur 3 (003MO) : Déplacement tige axe Y (Avance/Recul horizontal)
static const uint8_t MEGA_003MO_STEP = 28;
static const uint8_t MEGA_003MO_DIR  = 29;
static const uint8_t MEGA_003MO_EN   = 30;

// Moteur 4 (004MO) : Tige rétractable (Vérin à vis)
static const uint8_t MEGA_004MO_STEP = 31;
static const uint8_t MEGA_004MO_DIR  = 32;
static const uint8_t MEGA_004MO_EN   = 33;


/**
 * ============================================================================
 * MICRORUPTEURS / FINS DE COURSE (001MR - 009MR)
 * ============================================================================
 * Doivent être configurés en INPUT_PULLUP dans le setup().
 * État logique : 
 * - LOW  (0) = Switch pressé (connecté physiquement à la masse GND).
 * - HIGH (1) = Switch relâché (tiré à 5V par la résistance interne).
 */
static const uint8_t MEGA_001MR_PIN  = 34;
static const uint8_t MEGA_002MR_PIN  = 35;
static const uint8_t MEGA_003MR_PIN  = 36;
static const uint8_t MEGA_004MR_PIN  = 37;
static const uint8_t MEGA_005MR_PIN  = 38;
static const uint8_t MEGA_006MR_PIN  = 39;
static const uint8_t MEGA_007MR_PIN  = 40;
static const uint8_t MEGA_008MR_PIN  = 41;
static const uint8_t MEGA_009MR_PIN  = 42;


/**
 * ============================================================================
 * ALARMES DRIVERS (ALM MOTEURS)
 * ============================================================================
 * Signal de défaut (Fault) remonté par chaque driver moteur (bloqué, surchauffe).
 * Doivent être configurés en INPUT_PULLUP.
 * État logique : Actif à LOW si le driver se met en sécurité.
 */
static const uint8_t MEGA_001MO_ALM = 8;  // Alarme Colonne Z
// Le moteur 2 n'a pas de pin ALM déclaré
static const uint8_t MEGA_003MO_ALM = 9;  // Alarme Axe Y
static const uint8_t MEGA_004MO_ALM = 10; // Alarme Vérin à vis

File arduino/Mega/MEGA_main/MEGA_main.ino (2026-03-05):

/**
 * ============================================================================
 * FICHIER : MEGA_main.ino (V6 - Final & Clean)
 * ROLE    : Gestion 4 Moteurs + 4 Capteurs INA260 + Double Sécurité (Min/Max)
 * + Remontée des alarmes drivers (ALM) vers ROS 2.
 * ============================================================================
 */

#include <AccelStepper.h>
#include <ArduinoJson.h>
#include <Wire.h>
#include <Adafruit_INA260.h>
#include "pins_mega.h" // Le mapping matériel détaillé

/**
 * ============================================================================
 * CONFIGURATION ET PARAMÈTRES
 * ============================================================================
 */
const bool HAS_INA260 = true; 

// Adresses I2C des 4 capteurs de puissance
#define ADDR_INA1 0x40 // Rien soudé
#define ADDR_INA2 0x41 // A0 soudé
#define ADDR_INA3 0x44 // A1 soudé
#define ADDR_INA4 0x45 // A0 + A1 soudés

// Fréquences d'envoi de la télémétrie (en millisecondes)
const unsigned long TELEMETRY_FAST_MS = 100; // 10 Hz (Positions, Fins de course, Alarmes)
const unsigned long TELEMETRY_SLOW_MS = 500; // 2 Hz  (Consommation INA260)

/**
 * ============================================================================
 * MAPPING DES FINS DE COURSE (PAIRES MIN/MAX)
 * ============================================================================
 */
// Moteur 1 (Colonne Z)
#define PIN_M1_MIN MEGA_001MR_PIN // Pin 34
#define PIN_M1_MAX MEGA_002MR_PIN // Pin 35

// Moteur 2 (Stockage)
#define PIN_M2_MIN MEGA_003MR_PIN // Pin 36
#define PIN_M2_MAX MEGA_004MR_PIN // Pin 37

// Moteur 3 (Tige Y)
#define PIN_M3_MIN MEGA_005MR_PIN // Pin 38
#define PIN_M3_MAX MEGA_006MR_PIN // Pin 39

// Moteur 4 (Vérin rétractable)
#define PIN_M4_MIN MEGA_007MR_PIN // Pin 40
#define PIN_M4_MAX MEGA_008MR_PIN // Pin 41

/**
 * ============================================================================
 * VARIABLES GLOBALES ET OBJETS
 * ============================================================================
 */
// Initialisation des moteurs
AccelStepper ST1(AccelStepper::DRIVER, MEGA_001MO_STEP, MEGA_001MO_DIR);
AccelStepper ST2(AccelStepper::DRIVER, MEGA_002MO_STEP, MEGA_002MO_DIR);
AccelStepper ST3(AccelStepper::DRIVER, MEGA_003MO_STEP, MEGA_003MO_DIR);
AccelStepper ST4(AccelStepper::DRIVER, MEGA_004MO_STEP, MEGA_004MO_DIR);

// Objets Capteurs de puissance
Adafruit_INA260 ina1, ina2, ina3, ina4;

// État de connexion des capteurs
bool ina1_ok = false, ina2_ok = false, ina3_ok = false, ina4_ok = false;

// Buffers de communication
JsonDocument docRx;
JsonDocument docTx;

// Timers
unsigned long lastFastTelem = 0;
unsigned long lastSlowTelem = 0;

// Prototype fonction sécurité
void checkAndRunDual(AccelStepper &stepper, uint8_t pinMin, uint8_t pinMax, uint8_t hitState = LOW);
/**
 * ============================================================================
 * SETUP : INITIALISATION
 * ============================================================================
 */
void setup() {
  Serial.begin(115200);

  // --- 1. Init Pins Enable (Sorties) ---
  pinMode(MEGA_001MO_EN, OUTPUT);
  pinMode(MEGA_002MO_EN, OUTPUT);
  pinMode(MEGA_003MO_EN, OUTPUT);
  pinMode(MEGA_004MO_EN, OUTPUT);

  // --- 2. Init Pins Fins de course (Entrées avec Pullup) ---
  pinMode(PIN_M1_MIN, INPUT_PULLUP); pinMode(PIN_M1_MAX, INPUT_PULLUP);
  pinMode(PIN_M2_MIN, INPUT_PULLUP); pinMode(PIN_M2_MAX, INPUT_PULLUP);
  pinMode(PIN_M3_MIN, INPUT_PULLUP); pinMode(PIN_M3_MAX, INPUT_PULLUP);
  pinMode(PIN_M4_MIN, INPUT_PULLUP); pinMode(PIN_M4_MAX, INPUT_PULLUP);

  // --- 3. Init Pins d'Alarme Drivers (ALM) ---
  // (La coupure se fait en hard dans le driver, l'Arduino ne fait que lire)
  pinMode(MEGA_001MO_ALM, INPUT_PULLUP); // Pin 8
  pinMode(MEGA_003MO_ALM, INPUT_PULLUP); // Pin 9
  pinMode(MEGA_004MO_ALM, INPUT_PULLUP); // Pin 10

  // --- 4. Init Steppers ---
  // (Inversion Enable : true car souvent actif à LOW sur drivers type DM542/TB6600)
  ST1.setPinsInverted(false, false, true);
  ST2.setPinsInverted(false, false, true);
  ST3.setPinsInverted(false, false, true);
  ST4.setPinsInverted(false, false, true);

  // Vitesses et Accélérations par défaut
  ST1.setMaxSpeed(1500); ST1.setAcceleration(1000);
  ST2.setMaxSpeed(1500); ST2.setAcceleration(1000);
  ST3.setMaxSpeed(1500); ST3.setAcceleration(1000);
  ST4.setMaxSpeed(1500); ST4.setAcceleration(1000);

  ST1.enableOutputs(); 
  ST2.enableOutputs(); 
  ST3.enableOutputs(); 
  ST4.enableOutputs();

  // --- 5. Init Capteurs INA260 ---
  if (HAS_INA260) {
    if (ina1.begin(ADDR_INA1)) ina1_ok = true;
    if (ina2.begin(ADDR_INA2)) ina2_ok = true;
    if (ina3.begin(ADDR_INA3)) ina3_ok = true;
    if (ina4.begin(ADDR_INA4)) ina4_ok = true;
  }

  Serial.println(F("{\"event\":\"boot\",\"status\":\"ready_v6\"}"));
}

/**
 * ============================================================================
 * LOOP : BOUCLE PRINCIPALE
 * ============================================================================
 */
void loop() {
  
// --- 1. GESTION DES MOTEURS + DOUBLE SÉCURITÉ ---
  checkAndRunDual(ST1, PIN_M1_MIN, PIN_M1_MAX, LOW);
  checkAndRunDual(ST2, PIN_M2_MIN, PIN_M2_MAX, LOW);
  checkAndRunDual(ST3, PIN_M3_MIN, PIN_M3_MAX, LOW);
  checkAndRunDual(ST4, PIN_M4_MIN, PIN_M4_MAX, HIGH);
  // --- 2. LECTURE SÉRIE ---
  if (Serial.available() > 0) {
    String input = Serial.readStringUntil('\n');
    input.trim();
    if (input.length() > 0) handleCmd(input);
  }

  // --- 3. TÉLÉMÉTRIE RAPIDE (Positions, FdC, Alarmes) ---
  if (millis() - lastFastTelem > TELEMETRY_FAST_MS) {
    lastFastTelem = millis();
    sendPositions();
    sendLimits();
  }

  // --- 4. TÉLÉMÉTRIE LENTE (Puissance) ---
  if (HAS_INA260 && (millis() - lastSlowTelem > TELEMETRY_SLOW_MS)) {
    lastSlowTelem = millis();
    sendPower();
  }
}

/**
 * ============================================================================
 * FONCTIONS : SÉCURITÉ & CONTRÔLE
 * ============================================================================
 */

/**
 * @brief Vérifie les fins de course et autorise ou bloque le mouvement
 */
void checkAndRunDual(AccelStepper &stepper, uint8_t pinMin, uint8_t pinMax, uint8_t hitState) {
  bool hit_min = (digitalRead(pinMin) == hitState); // <--- UTILISE LE NOUVEL ÉTAT
  bool hit_max = (digitalRead(pinMax) == hitState); // <--- UTILISE LE NOUVEL ÉTAT
  
  long distance = stepper.distanceToGo(); 

  if (hit_min && distance < 0) {
      stepper.setCurrentPosition(stepper.currentPosition());
  } 
  else if (hit_max && distance > 0) {
      stepper.setCurrentPosition(stepper.currentPosition());
  } 
  
  stepper.run();
}
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

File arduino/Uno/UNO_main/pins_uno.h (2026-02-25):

#pragma once
#include <Arduino.h>

/**
 * ============================================================================
 * FICHIER : pins_uno.h
 * ROLE    : Définition du mapping matériel (broches) pour l'Arduino Uno.
 * Centralise toutes les connexions pour les actionneurs secondaires, relais, 
 * servos et capteurs I2C.
 * ============================================================================
 */

/* --- IDENTIFICATION DU NŒUD --- */
#define UNO_BOARD_ID    "002UC_ARDUINO_UNO"
#define UNO_FW_VERSION  "1.0"


/**
 * ============================================================================
 * BUS I2C (CENTRALE INERTIELLE 001CI)
 * ============================================================================
 * SDA = Ligne de données (A4 sur Uno)
 * SCL = Ligne d'horloge (A5 sur Uno)
 */
static const uint8_t UNO_I2C_SDA = A4;
static const uint8_t UNO_I2C_SCL = A5;


/**
 * ============================================================================
 * RELAIS / TRANSISTORS (001XR à 006XR)
 * ============================================================================
 * Contrôle des équipements de puissance (lumières, pompe, électrovannes).
 * Généralement actifs à l'état HIGH (1), selon le module relais utilisé.
 */
static const uint8_t UNO_001XR_PIN = 12; // Ruban LED Blanc
static const uint8_t UNO_002XR_PIN = 13; // Ruban LED RGB (Général)
static const uint8_t UNO_003XR_PIN = 7;  // Aspirateur / Pompe
static const uint8_t UNO_004XR_PIN = 2;  // Électrovanne 1 (À tester)
static const uint8_t UNO_005XR_PIN = 5;  // Électrovanne 2 (À tester)
static const uint8_t UNO_006XR_PIN = 6;  // Électrovanne 3


/**
 * ============================================================================
 * SERVOMOTEURS (001SV à 004SV)
 * ============================================================================
 * Contrôle PWM via la librairie Servo.h.
 */
static const uint8_t UNO_001SV_PIN = 3;  // Rotation Caméra (Axe Z / Pan)
static const uint8_t UNO_002SV_PIN = 4;  // Rotation Caméra (Axe Y / Tilt)
static const uint8_t UNO_003SV_PIN = 11; // Rotation Pince (Poignet)
static const uint8_t UNO_004SV_PIN = 9;  // Serrage Pince (Préhension)


/**
 * ============================================================================
 * CAPTEURS ET ENTRÉES
 * ============================================================================
 */
static const uint8_t UNO_001FC_PIN = A0; // Fin de course (Serrage Pince)


/**
 * ============================================================================
 * RUBAN LED ADRESSABLE (NEOPIXEL / WS2812B)
 * ============================================================================
 * Contrôle d'un ruban LED intelligent (chaque LED est indépendante).
 */
static const uint8_t UNO_001LED_PIN   = 8;   // Broche Data du ruban
static const uint16_t UNO_001LED_COUNT = 115; // Nombre total de LEDs sur le ruban

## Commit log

2025-11-21 Backup ROS2 propre
    [URDF_v5.SLDASM.urdf, URDF_v6.SLDASM.urdf, base.STL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]
2026-02-02 Ajout du dossier Arduino via sparse-checkout
2026-02-04 maj pin mega
2026-02-06 MAJ drivers
2026-02-11 pin mod
2026-02-19 Correction de la balise Mermaid et formatage du README
2026-02-23 Ajout CSV et relay
2026-02-25 LED RGB Blanche au démarrage + fin de course pince
2026-02-25 LED RGB Blanche au démarrage + fin de course pince
    Updated the LED count for the addressable LED strip.
2026-02-26 Réglage intensité LED setup
2026-03-05 Version soutenance
    [IMU.STL, base.STL, base_old.STL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]
